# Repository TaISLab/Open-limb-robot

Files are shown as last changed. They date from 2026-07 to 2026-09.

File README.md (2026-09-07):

# Open-Limb Robot

Open, non-anthropomorphic robot that orbits around a compliant cylindrical surface — such as a human limb or a pipe — with a three-contact grasp: a central traction module with two in-line driven wheels, and two lateral spring-loaded arms with distal wheels.

This repository accompanies the paper:

> L. M. Tobar-Subia-Contento, J. A. Cabrera, A. Mandow, and J. M. Gómez-de-Gabriel, "On-Limb Orbiting Robot: Proprioceptive Diameter Estimation and Orthogonal Grip–Orbit Control," submitted to *Biomimetics* (MDPI), 2026.

The central contribution is an actuation-space decomposition in which the two lateral wheel torques, expressed in a common-mode/differential basis, simultaneously drive the orbital motion and regulate the central normal force — orthogonally and without a dedicated force mechanism. The same compliant arms yield a closed-form estimate of the cylinder diameter from proprioception alone.

## Demonstration video

<video src="https://github.com/TaISLab/Open-limb-robot/raw/main/media/On-Limb-Orbiting-Robot.mp4" controls width="600"></video>

## Repository structure

```
Open-limb-robot/
├── CAD/                      # SolidWorks design files and STL/STEP exports
├── experiments/              # Data and processing scripts from the prototype tests
├── simulation/
│   ├── lib/                  # Shared geometry functions
│   └── scripts/              # Runnable analysis scripts
├── media/                    # Demonstration video and funding logo
├── LICENSE
└── README.md
```

### `CAD/`
SolidWorks design files for the Mobile Platform (MP), the central traction module and the lateral grasping arms, plus exported files ready for 3D printing in PETG. Mechanical design parameters are listed in Table 1 of the paper.

### `simulation/`

`lib/` contains the shared geometry functions used by all scripts:

| Function | Implements |
|---|---|
| `contactDepth.m` | Averaged central contact depth, Eq. (1) |
| `radiusEstimator.m` | Closed-form cylinder-radius estimator, Eq. (3) |
| `lateralContactAngle.m` | Lateral-contact angle γ, Eq. (4) |
| `solveArmAngle.m` | Numerical inversion of Eq. (3) for a known radius |

`scripts/` contains the runnable analyses:

| Script | Reproduces |
|---|---|
| `static_force_model_01.m` | Static force model and actuation-space decomposition (Sections 4–5); numerically verifies that the common-mode/differential basis diagonalises the force map, Eq. (20) |
| `orbital_simulation_02.m` | Closed-loop orbital simulation over a full revolution (Section 8.3, Figure 9, Table 2) |
| `radius_estimator_sensitivity_03.m` | Radius-estimator sensitivity analysis (Sections 4.3 and 8.2, Figure 8) |

Scripts add `../lib` to the path automatically. Run them from the `simulation/scripts/` folder.

**Reproducing the feedforward-only vs. feedforward+PI comparison (Table 2).** In `orbital_simulation_02.m`, set the `has_force_sensor` flag to `false` to disable the PI correction and to `true` for the nominal configuration reported in Figure 9.

### `experiments/`
Data and processing scripts from the preliminary prototype tests (Section 8.4): spring characteristic and contact-force calibration (Figure 7), grasp-retention test across orbital orientations (Figure 10), and open-loop orbital-rotation tests for different assumed friction coefficients (Figure 11).

## Hardware

- Actuation: DYNAMIXEL XC330-T288-T servo (grasping actuator), DC motors (drive wheels)
- Sensing: rotational springs with angular sensors (central compliant contact), servo encoder (arm angle), IMU (orbital angle)
- Chassis: 3D-printed PETG

## Requirements

MATLAB (developed with R2023b or later; no toolboxes beyond base MATLAB are required). The scripts also run under GNU Octave.

For CAD source files, SolidWorks; the exported STL/STEP files can be opened with any standard CAD viewer.

## Citation

If you use this code or design in your research, please cite the paper above. A full citation with DOI will be added once the manuscript is published.

## License

Released under the [MIT License](LICENSE).

## Funding

<p align="center">
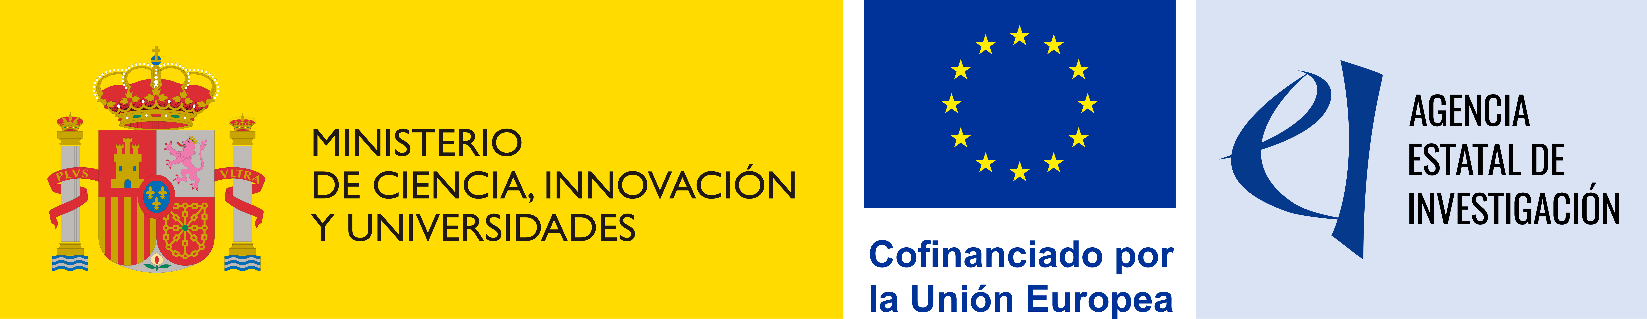
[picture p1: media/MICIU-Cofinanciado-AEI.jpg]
MICIU / AEI / FEDER
  
</p>

<p align="center">
This work is part of project PID2021-127221OB-I00 (CONCERTO — Control Colaborativo para Interacción física Empática entre RoboT y humanO), funded by MICIU/AEI/10.13039/501100011033/FEDER, UE.
</p>

## Contact

Jesús M. Gómez-de-Gabriel — jesus.gomez@uma.es
Institute for Mechatronics Engineering and Cyber-Physical Systems (IMECH.UMA), Universidad de Málaga

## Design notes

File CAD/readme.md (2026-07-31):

============================================================
README – CAD MODEL OF THE ON-LIMB ORBITING ROBOT
============================================================

1. RESOURCE TITLE

CAD model and complete mechanical assembly of the On-Limb
Orbiting Robot.

2. ASSOCIATED PUBLICATION

On-Limb Orbiting Robot: Proprioceptive Diameter Estimation
and Orthogonal Grip–Orbit Control

3. AUTHORS

Luz M. Tobar-Subia-Contento
Juan A. Cabrera
Anthony Mandow
Jesús M. Gómez-de-Gabriel

4. AFFILIATIONS

Faculty of Engineering in Applied Sciences (FICA),
Universidad Técnica del Norte, Ibarra, Ecuador.

Institute for Mechatronics Engineering and Cyber-Physical
Systems (IMECH.UMA), Universidad de Málaga, Málaga, Spain.

5. GENERAL DESCRIPTION

This resource contains the complete mechanical assembly of
the on-limb orbiting robot described in the associated
publication.

The complete assembly and its referenced component files are
provided in the following compressed archive:

OnLimbOrbitalRobot.zip

The original and official file names used during the
development of the robot have been preserved.

6. SOFTWARE USED

Software: SOLIDWORKS 2024
Edition: Academic Edition
Software licence: Academic licence provided by Universidad
de Málaga.

7. FILE ORGANIZATION

The file OnLimbOrbitalRobot.zip contains the complete
mechanical assembly and its associated component files.

Users should preserve the original directory structure and
file names when extracting the archive, as changing their
names or locations may affect the references between the
assembly and its components.

8. INSTRUCTIONS FOR USE

1. Download and extract the complete compressed archive.
2. Preserve the original directory structure.
3. Open the main assembly file using SOLIDWORKS 2024 or a
   compatible version.
4. Allow SOLIDWORKS to resolve the referenced component files
   from the extracted directory.

9. COMPATIBILITY

The files were created and verified using SOLIDWORKS 2024,
Academic Edition.

Compatibility with earlier SOLIDWORKS versions is not
guaranteed. Opening the files with a later version may update
their internal format and prevent subsequent use with
SOLIDWORKS 2024.

10. PURPOSE

The CAD files are provided to support the understanding,
inspection and reproducibility of the mechanical design
presented in the associated scientific publication.

11. RELATED DATASET

The experimental data associated with the validation of the
robot are available in the corresponding RIUMA dataset record.

RIUMA persistent identifier:
[TO BE ASSIGNED BY RIUMA]

12. REUSE LICENCE

The reuse licence for this resource will be specified in the
corresponding RIUMA repository record.

13. CONTACT

Luz M. Tobar-Subia-Contento
Universidad Técnica del Norte / Universidad de Málaga
E-mail: luztobar@uma.es
E-mail: lmtobarsubia@utn.edu.ec

Jesús M. Gómez-de-Gabriel
Universidad de Málaga
E-mail: jesus.gomez@uma.es

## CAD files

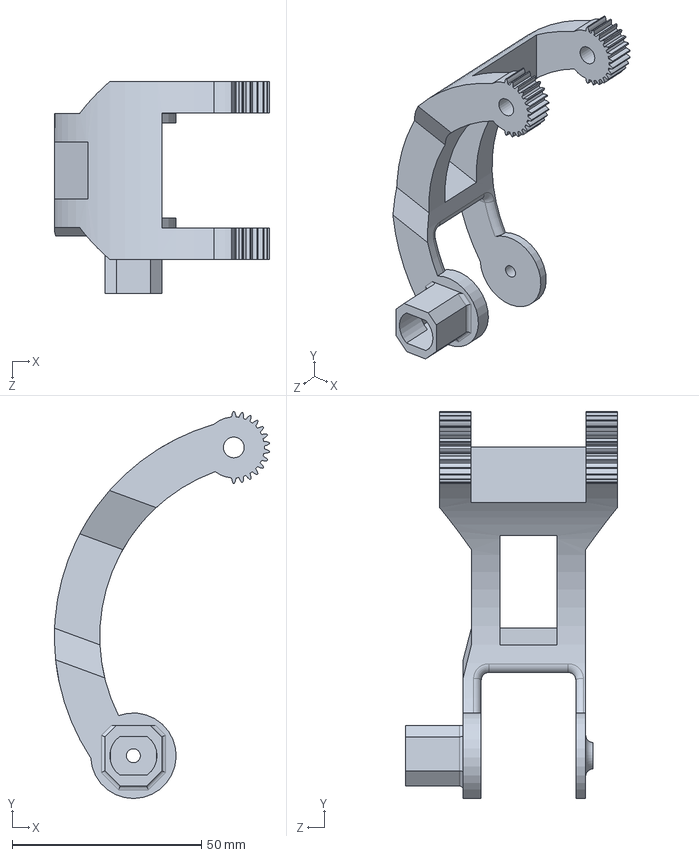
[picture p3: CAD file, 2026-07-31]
CAD/SolidWorks/arm-right.SLDPRT
56.9 x 102.3 x 56.0 mm

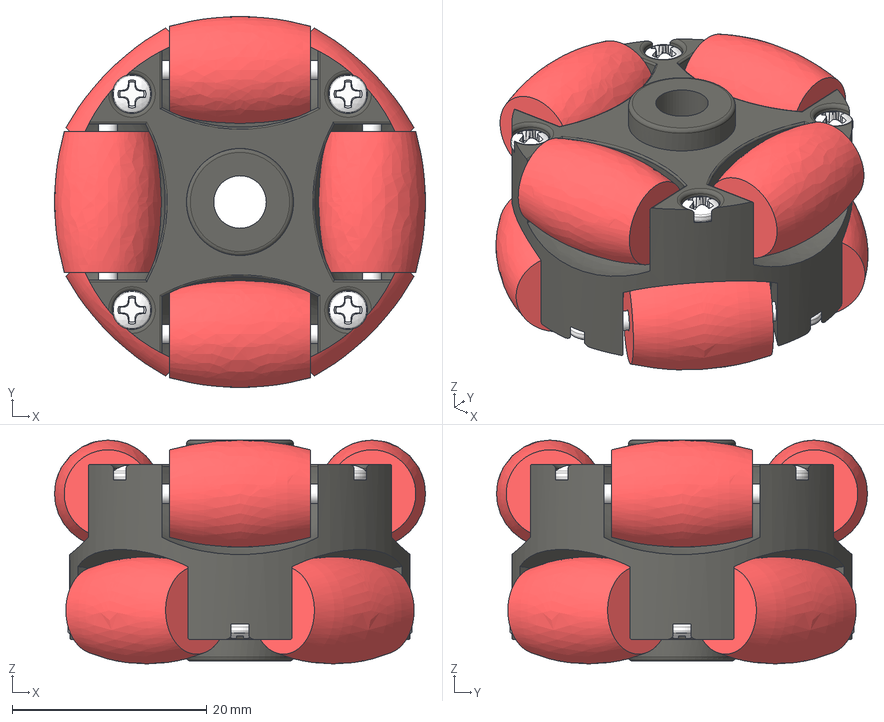
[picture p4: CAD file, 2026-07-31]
CAD/SolidWorks/omni wheel.step
38.1 x 38.1 x 23.0 mm
ролик x 8
92005A010_Steel Pan Head Phillips Screw x 8

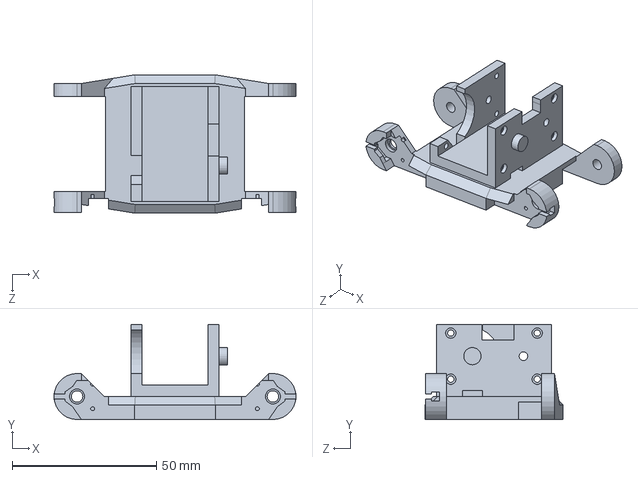
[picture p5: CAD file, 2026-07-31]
CAD/SolidWorks/MobilePlatform.SLDPRT
84.0 x 33.0 x 48.0 mm

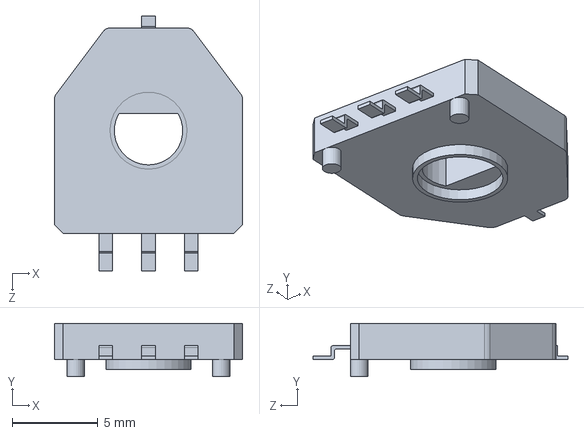
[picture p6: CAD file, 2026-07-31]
CAD/SolidWorks/MurataSV01.SLDPRT
11.0 x 3.10 x 14.9 mm

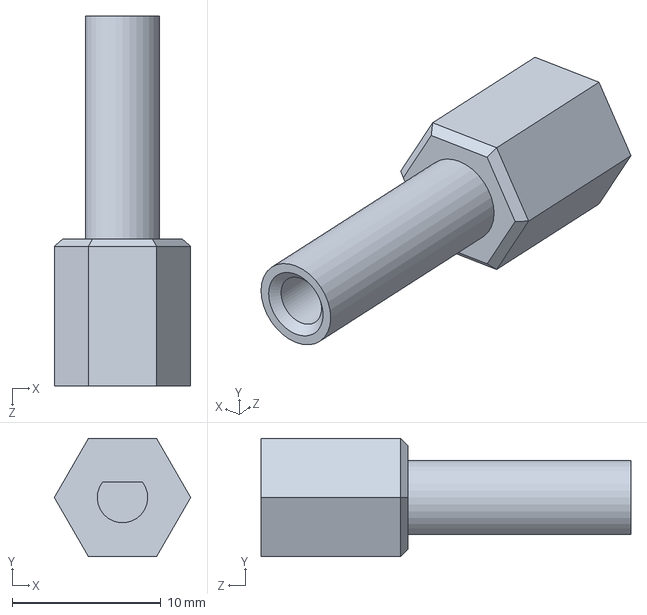
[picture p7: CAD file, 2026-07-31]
CAD/SolidWorks/hub-wheel-minimotor-metal.SLDPRT
9.18 x 7.95 x 24.9 mm

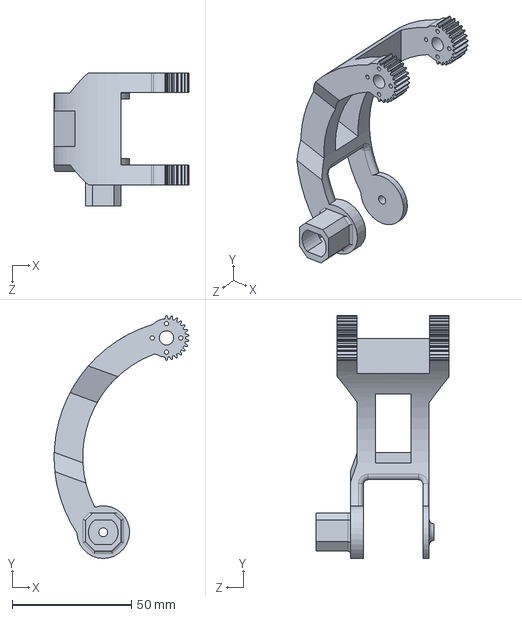
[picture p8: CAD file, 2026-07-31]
CAD/SolidWorks/arm-left.SLDPRT
56.5 x 101.9 x 56.0 mm

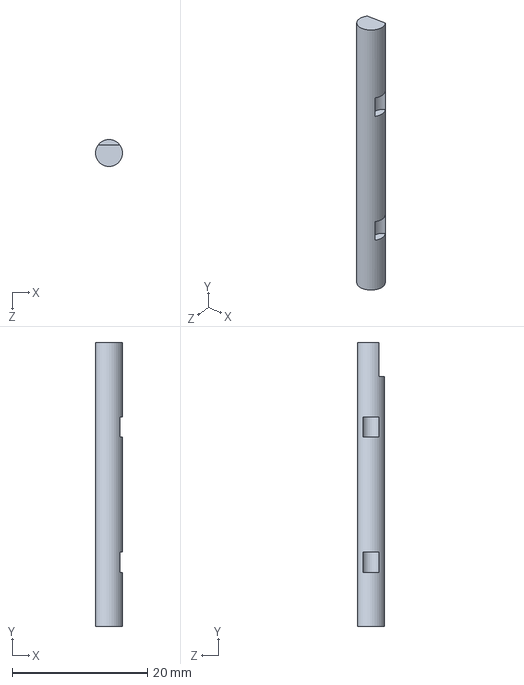
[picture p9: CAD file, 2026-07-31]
CAD/SolidWorks/eje 35x4.SLDPRT
3.98 x 42.0 x 4.00 mm

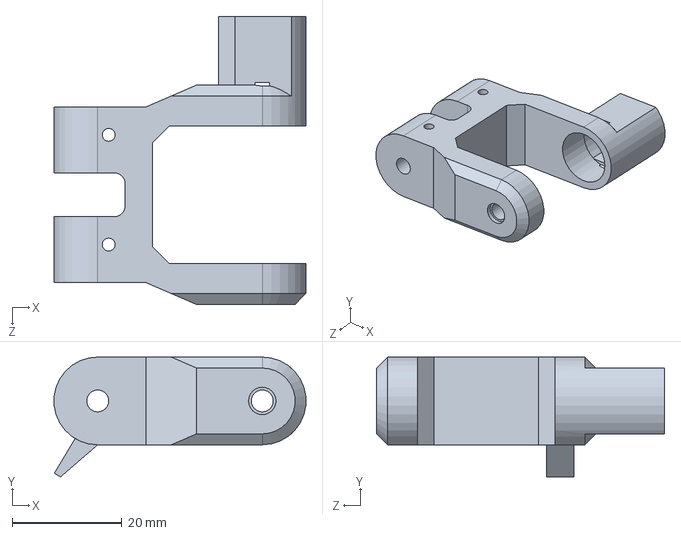
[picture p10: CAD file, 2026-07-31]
CAD/SolidWorks/SwingLinks.SLDPRT
45.9 x 21.9 x 52.5 mm

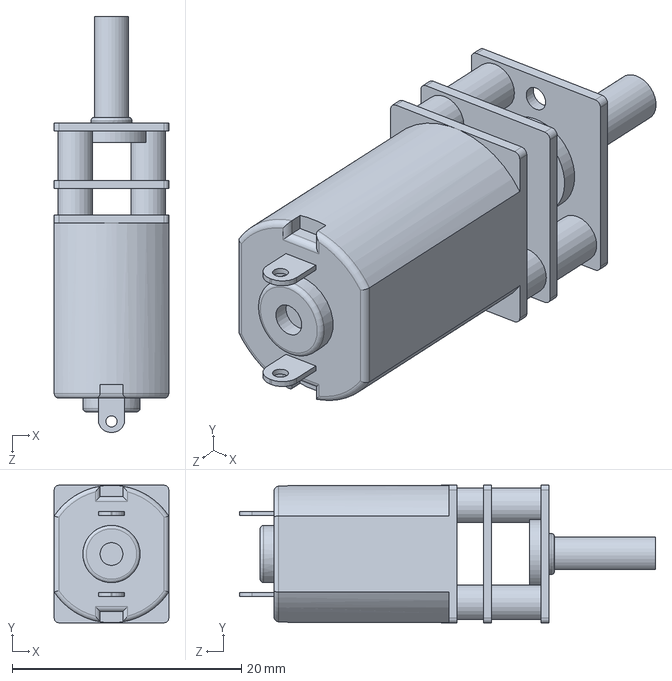
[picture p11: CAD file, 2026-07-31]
CAD/SolidWorks/MicromotorDC.SLDPRT
10.0 x 12.0 x 36.3 mm

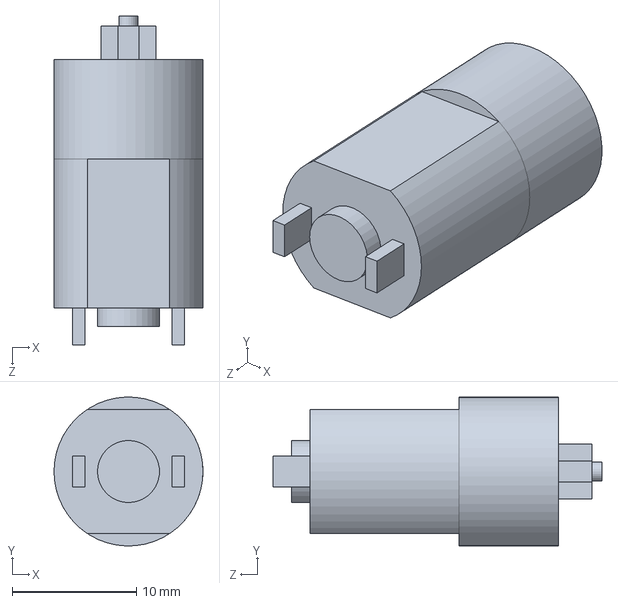
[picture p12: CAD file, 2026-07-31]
CAD/SolidWorks/motorDC_SwingLinks.SLDPRT
12.0 x 12.0 x 26.5 mm

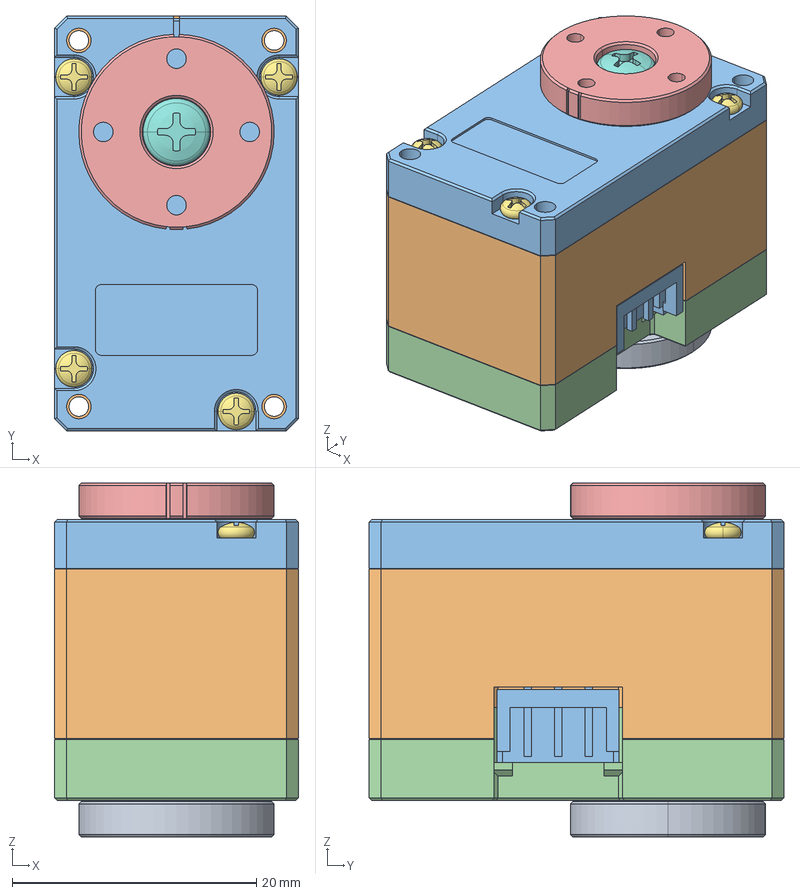
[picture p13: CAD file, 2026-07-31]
CAD/SolidWorks/XL,XC-330.stp
20.0 x 34.0 x 29.0 mm
DC15_A01_CASE_M_DUMMY
DC15_A01_CASE_F_DUMMY
DC15_A01_CASE_B_DUMMY
DC15_A01_HORN_DUMMY
DC15_A01_LED_CAP2_DUMMY
PHS_1_7X20_5_DC10 x 4
BTS2_M2_6X8 x 2
DC15_A01_HORN_IDLE2_DUMMY
DC15_A01_IDLE_CAP_DUMMY
B3B-EH x 2

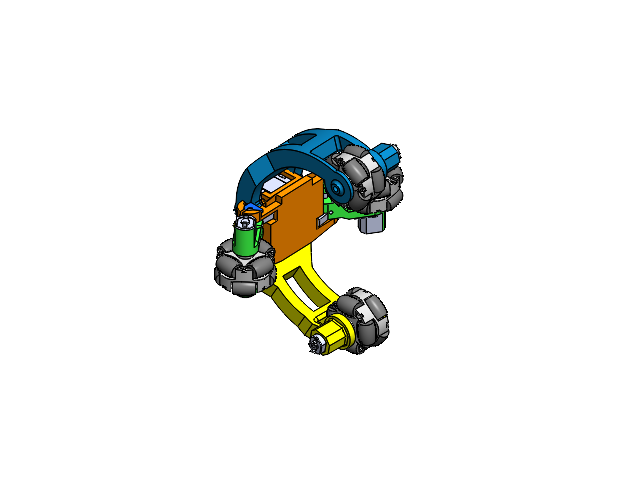
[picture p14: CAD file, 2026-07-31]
CAD/SolidWorks/OnLimbOrbitalRobot.SLDASM
arm-right
ролик.step x 32
92005A010_Steel Pan Head Phillips Screw.step x 32
колесо.step x 4
колесо-0.step x 4
колесо-1.step x 4
колесо-2.step x 4
колесо-3.step x 4
колесо-4.step x 4
колесо-5.step x 4
колесо-6.step x 4
колесо-7.step x 4
MobilePlatform
SwingLinks x 2
eje 35x4 x 2
MurataSV01 x 2
DC15_A01_CASE_M_DUMMY.stp
DC15_A01_CASE_F_DUMMY.stp
DC15_A01_CASE_B_DUMMY.stp
DC15_A01_HORN_DUMMY.stp
DC15_A01_LED_CAP2_DUMMY.stp
PHS_1_7X20_5_DC10.stp x 4
BTS2_M2_6X8.stp x 2
DC15_A01_HORN_IDLE2_DUMMY.stp
DC15_A01_IDLE_CAP_DUMMY.stp
B3B-EH_1.stp x 2
arm-left
motorDC_SwingLinks x 2
hub-wheel-minimotor-metal x 2
MicromotorDC x 2

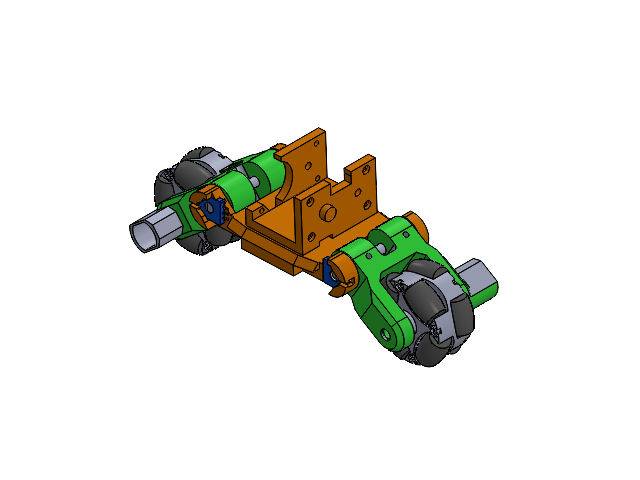
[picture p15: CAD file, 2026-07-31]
CAD/SolidWorks/CentraTractionModule.SLDASM
MobilePlatform
SwingLinks x 2
ролик.step x 16
92005A010_Steel Pan Head Phillips Screw.step x 16
колесо.step x 2
колесо-0.step x 2
колесо-1.step x 2
колесо-2.step x 2
колесо-3.step x 2
колесо-4.step x 2
колесо-5.step x 2
колесо-6.step x 2
колесо-7.step x 2
eje 35x4 x 2
MurataSV01 x 2

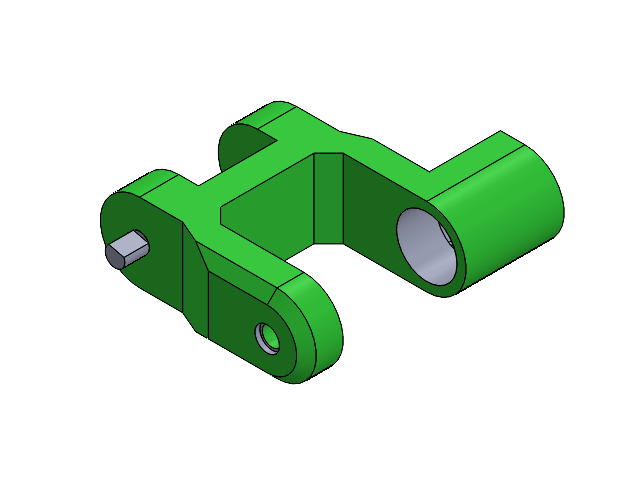
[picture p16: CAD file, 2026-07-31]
CAD/SolidWorks/SuspentionSystem.SLDASM
basculante lateral
ролик.step x 8
92005A010_Steel Pan Head Phillips Screw.step x 8
колесо.step
колесо-0.step
колесо-1.step
колесо-2.step
колесо-3.step
колесо-4.step
колесо-5.step
колесо-6.step
колесо-7.step
eje 35x4

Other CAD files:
CAD/SolidWorks/XL,XC-330.SLDASM
CAD/SolidWorks/omni wheel.SLDASM

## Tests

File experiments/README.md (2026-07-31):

## Dependencies

- MATLAB
- Arduino IDE
- Dynamixel SDK for MATLAB (Jonathon / ROBOTIS)
- Dynamixel USB interface

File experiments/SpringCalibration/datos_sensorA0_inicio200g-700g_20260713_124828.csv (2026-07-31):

Tiempo_s | ADC | Voltaje_V | Bloque | PesoProgramado_kg
0.000 | 509 | 2.487781 | 0 | 0.000000
0.100 | 509 | 2.487781 | 0 | 0.000000
0.200 | 508 | 2.482893 | 0 | 0.000000
0.300 | 508 | 2.482893 | 0 | 0.000000
0.400 | 509 | 2.487781 | 0 | 0.000000
0.500 | 508 | 2.482893 | 0 | 0.000000
0.600 | 508 | 2.482893 | 0 | 0.000000
0.700 | 509 | 2.487781 | 0 | 0.000000
0.800 | 508 | 2.482893 | 0 | 0.000000
0.900 | 508 | 2.482893 | 0 | 0.000000
1.000 | 509 | 2.487781 | 0 | 0.000000
1.100 | 509 | 2.487781 | 0 | 0.000000
1.200 | 509 | 2.487781 | 0 | 0.000000
1.300 | 508 | 2.482893 | 0 | 0.000000
1.400 | 508 | 2.482893 | 0 | 0.000000
1.500 | 509 | 2.487781 | 0 | 0.000000
1.600 | 508 | 2.482893 | 0 | 0.000000
1.700 | 509 | 2.487781 | 0 | 0.000000
1.800 | 509 | 2.487781 | 0 | 0.000000
1.900 | 509 | 2.487781 | 0 | 0.000000
2.000 | 509 | 2.487781 | 0 | 0.000000
2.100 | 508 | 2.482893 | 0 | 0.000000
2.200 | 508 | 2.482893 | 0 | 0.000000
2.300 | 509 | 2.487781 | 0 | 0.000000
2.400 | 508 | 2.482893 | 0 | 0.000000
2.500 | 508 | 2.482893 | 0 | 0.000000
2.600 | 508 | 2.482893 | 0 | 0.000000
2.700 | 508 | 2.482893 | 0 | 0.000000
2.800 | 509 | 2.487781 | 0 | 0.000000
2.900 | 508 | 2.482893 | 0 | 0.000000
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

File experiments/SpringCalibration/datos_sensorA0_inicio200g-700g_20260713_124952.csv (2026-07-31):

Tiempo_s | ADC | Voltaje_V | Bloque | PesoProgramado_kg
0.000 | 504 | 2.463343 | 0 | 0.000000
0.100 | 503 | 2.458456 | 0 | 0.000000
0.200 | 503 | 2.458456 | 0 | 0.000000
0.300 | 503 | 2.458456 | 0 | 0.000000
0.400 | 503 | 2.458456 | 0 | 0.000000
0.500 | 503 | 2.458456 | 0 | 0.000000
0.600 | 503 | 2.458456 | 0 | 0.000000
0.700 | 503 | 2.458456 | 0 | 0.000000
0.800 | 503 | 2.458456 | 0 | 0.000000
0.901 | 503 | 2.458456 | 0 | 0.000000
1.000 | 503 | 2.458456 | 0 | 0.000000
1.100 | 503 | 2.458456 | 0 | 0.000000
1.200 | 503 | 2.458456 | 0 | 0.000000
1.300 | 503 | 2.458456 | 0 | 0.000000
1.400 | 503 | 2.458456 | 0 | 0.000000
1.500 | 504 | 2.463343 | 0 | 0.000000
1.600 | 503 | 2.458456 | 0 | 0.000000
1.700 | 503 | 2.458456 | 0 | 0.000000
1.800 | 503 | 2.458456 | 0 | 0.000000
1.900 | 503 | 2.458456 | 0 | 0.000000
2.000 | 504 | 2.463343 | 0 | 0.000000
2.100 | 503 | 2.458456 | 0 | 0.000000
2.200 | 503 | 2.458456 | 0 | 0.000000
2.300 | 503 | 2.458456 | 0 | 0.000000
2.400 | 503 | 2.458456 | 0 | 0.000000
2.500 | 503 | 2.458456 | 0 | 0.000000
2.600 | 503 | 2.458456 | 0 | 0.000000
2.700 | 503 | 2.458456 | 0 | 0.000000
2.800 | 503 | 2.458456 | 0 | 0.000000
2.900 | 503 | 2.458456 | 0 | 0.000000
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

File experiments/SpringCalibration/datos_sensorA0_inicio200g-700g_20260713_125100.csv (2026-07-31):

Tiempo_s | ADC | Voltaje_V | Bloque | PesoProgramado_kg
0.000 | 501 | 2.448680 | 0 | 0.000000
0.100 | 501 | 2.448680 | 0 | 0.000000
0.200 | 501 | 2.448680 | 0 | 0.000000
0.300 | 501 | 2.448680 | 0 | 0.000000
0.400 | 501 | 2.448680 | 0 | 0.000000
0.500 | 501 | 2.448680 | 0 | 0.000000
0.600 | 501 | 2.448680 | 0 | 0.000000
0.701 | 501 | 2.448680 | 0 | 0.000000
0.800 | 501 | 2.448680 | 0 | 0.000000
0.900 | 501 | 2.448680 | 0 | 0.000000
1.000 | 501 | 2.448680 | 0 | 0.000000
1.100 | 501 | 2.448680 | 0 | 0.000000
1.200 | 501 | 2.448680 | 0 | 0.000000
1.300 | 501 | 2.448680 | 0 | 0.000000
1.400 | 501 | 2.448680 | 0 | 0.000000
1.500 | 501 | 2.448680 | 0 | 0.000000
1.600 | 501 | 2.448680 | 0 | 0.000000
1.700 | 501 | 2.448680 | 0 | 0.000000
1.800 | 501 | 2.448680 | 0 | 0.000000
1.900 | 501 | 2.448680 | 0 | 0.000000
2.000 | 501 | 2.448680 | 0 | 0.000000
2.100 | 501 | 2.448680 | 0 | 0.000000
2.200 | 501 | 2.448680 | 0 | 0.000000
2.300 | 501 | 2.448680 | 0 | 0.000000
2.400 | 501 | 2.448680 | 0 | 0.000000
2.500 | 501 | 2.448680 | 0 | 0.000000
2.600 | 501 | 2.448680 | 0 | 0.000000
2.700 | 501 | 2.448680 | 0 | 0.000000
2.800 | 501 | 2.448680 | 0 | 0.000000
2.900 | 501 | 2.448680 | 0 | 0.000000
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

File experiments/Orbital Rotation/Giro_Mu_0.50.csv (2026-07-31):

Tiempo_s | Phi_rel_deg | Phi_raw_deg | AX_g | AY_g | AZ_g | A0_V | A2_V | Theta0_raw | Theta0_filtrado | DXL_Corriente_mA | DXL_Corriente_abs_mA | DXL_Posicion_pulsos | DXL_Posicion_deg | DXL_Goal_Position_deg | Pulsos_Objetivo | Edad_dato_Arduino_s | Tau_calculado_Nmm | Corriente_calculada_mA | Test_ID | Motivo_detencion
0.000269586 | 4.22189162667941 | 10.387 | 0.4792 | -0.0085 | 1.0325 | 2.683 | 2.278 | 1.32696087626722 | 1.32696087626722 | -170 | 170 | 1889 | 166.025390625 | 127.265625 | 0 | 0 | 6.1520536592641 | 142.740916225447 | Giro_Off_intento5_180deg_2000_pulsos_Mu_0.50 | TIEMPO_MAXIMO
0.060174286 | 4.90289162667941 | 11.068 | 0.5554 | 0.0325 | 0.9949 | 2.678 | 2.297 | 1.33680909543189 | 1.32942293105839 | -146 | 146 | 1889 | 166.025390625 | 127.265625 | 255 | 0 | 10.3608510678253 | 146.400740058979 | Giro_Off_intento5_180deg_2000_pulsos_Mu_0.50 | TIEMPO_MAXIMO
0.130421017 | 5.80889162667941 | 11.974 | 0.5171 | -0.0154 | 1.0347 | 2.678 | 2.307 | 1.33680909543189 | 1.33126947215176 | -149 | 149 | 1889 | 166.025390625 | 127.265625 | 255 | 0 | 15.9534701547847 | 151.263887091117 | Giro_Off_intento5_180deg_2000_pulsos_Mu_0.50 | TIEMPO_MAXIMO
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

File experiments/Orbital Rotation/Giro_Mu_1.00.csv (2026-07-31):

Tiempo_s | Phi_rel_deg | Phi_raw_deg | AX_g | AY_g | AZ_g | A0_V | A2_V | Theta0_raw | Theta0_filtrado | DXL_Corriente_mA | DXL_Corriente_abs_mA | DXL_Posicion_pulsos | DXL_Posicion_deg | DXL_Goal_Position_deg | Pulsos_Objetivo | Edad_dato_Arduino_s | Tau_calculado_Nmm | Corriente_calculada_mA | Test_ID | Motivo_detencion
0.000142116 | 3.17165291102728 | 10.377 | 0.4646 | -0.012 | 1.0271 | 2.678 | 2.258 | 1.48604499845895 | 1.48604499845895 | -139 | 139 | 1891 | 166.201171875 | 127.44140625 | 0 | 0 | 9.82710586343877 | 128.545309446469 | Giro_Off_intento4_180deg_2000_pulsos_Mu_1.00 | TIEMPO_MAXIMO
0.055760852 | 3.99265291102728 | 11.198 | 0.5815 | -0.0212 | 1.0254 | 2.674 | 2.263 | 1.49741447210711 | 1.48888736687099 | -130 | 130 | 1891 | 166.201171875 | 127.44140625 | 255 | 0 | 12.3672122446618 | 130.754097604054 | Giro_Off_intento4_180deg_2000_pulsos_Mu_1.00 | TIEMPO_MAXIMO
0.103741667 | 4.89765291102728 | 12.103 | 0.4856 | -0.0093 | 1.022 | 2.678 | 2.268 | 1.48604499845895 | 1.48817677476798 | -131 | 131 | 1891 | 166.201171875 | 127.44140625 | 255 | 0 | 15.1642448704303 | 133.186299887331 | Giro_Off_intento4_180deg_2000_pulsos_Mu_1.00 | TIEMPO_MAXIMO
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

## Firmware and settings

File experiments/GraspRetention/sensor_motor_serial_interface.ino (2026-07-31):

#include <Wire.h>

// ========================================================
// PINES
// ========================================================
const int IN1 = 6;
const int IN2 = 7;
const int IN3 = 11;
const int IN4 = 10;

const int ENC1_A = 2;
const int ENC1_B = 4;
const int ENC2_A = 3;
const int ENC2_B = 5;

// ========================================================
// VARIABLES GLOBALES: CONTROL EN BUCLE ABIERTO Y ESTADO
// ========================================================
volatile long encoder1Pos = 0;
volatile long encoder2Pos = 0;

uint8_t mpuAddress = 0;

bool motorsActive = false;

// Se conserva para mantener la compatibilidad con el comando START.
// En bucle abierto, únicamente se utiliza su signo para definir el sentido.
long targetPos = 0;

// 1 = Ida, -1 = Retorno
int currentDirection = 1;

// PWM constante aplicado durante las pruebas en bucle abierto
const int FIXED_PWM = 255;

float phi_complementario = 0.0;

unsigned long lastTime = 0;

// Intervalo de actualización del accionamiento y la telemetría [ms]
const unsigned long CONTROL_INTERVAL = 10;

// ========================================================
// FUNCIONES DE COMUNICACIÓN I2C
// ========================================================
bool escribirRegistro(
  uint8_t direccion,
  uint8_t registro,
  uint8_t valor
) {
  Wire.beginTransmission(direccion);
  Wire.write(registro);
  Wire.write(valor);

  return Wire.endTransmission() == 0;
}

bool leerRegistro(
  uint8_t direccion,
  uint8_t registro,
  uint8_t &valor
) {
  Wire.beginTransmission(direccion);
  Wire.write(registro);

  if (Wire.endTransmission(false) != 0) {
    return false;
  }

  if (Wire.requestFrom(direccion, (uint8_t)1) != 1) {
    return false;
  }

  valor = Wire.read();
  return true;
}

// ========================================================
// INTERRUPCIONES DE LOS ENCODERS
// ========================================================
void readEncoder1() {
  if (digitalRead(ENC1_B) == HIGH) {
    encoder1Pos++;
  } else {
    encoder1Pos--;
  }
}

void readEncoder2() {
  if (digitalRead(ENC2_B) == HIGH) {
    encoder2Pos++;
  } else {
    encoder2Pos--;
  }
}

// ========================================================
// CONFIGURACIÓN INICIAL
// ========================================================
void setup() {
  Serial.begin(115200);

  pinMode(IN1, OUTPUT);
  pinMode(IN2, OUTPUT);
  pinMode(IN3, OUTPUT);
  pinMode(IN4, OUTPUT);

  stopAllMotors();

  pinMode(ENC1_A, INPUT_PULLUP);
  pinMode(ENC2_A, INPUT_PULLUP);

  attachInterrupt(
    digitalPinToInterrupt(ENC1_A),
    readEncoder1,
    RISING
  );

  attachInterrupt(
    digitalPinToInterrupt(ENC2_A),
    readEncoder2,
    RISING
  );

  Wire.begin();
  Wire.setClock(100000);

  if (!detectarMPU6050()) {
    // El programa permanece bloqueado si no se detecta el sensor.
    while (true) {
      delay(1000);
    }
  }

  escribirRegistro(
    mpuAddress,
    0x6B,
    0x00
  );  // Activar el MPU6050

  escribirRegistro(
    mpuAddress,
    0x1C,
    0x00
  );  // Configurar el acelerómetro en ±2 g
}

// ========================================================
// BUCLE PRINCIPAL
// ========================================================
void loop() {
  unsigned long currentTime = millis();

  checkSerialCommands();

  if (currentTime - lastTime >= CONTROL_INTERVAL) {
    lastTime = currentTime;

    int appliedPWM = 0;

    if (motorsActive) {
      // Funcionamiento en bucle abierto:
      // el PWM no depende de los encoders ni de un error de posición.
      appliedPWM = currentDirection * FIXED_PWM;

      setMotorPWM(1, appliedPWM);
      setMotorPWM(2, appliedPWM);
    } else {
      stopAllMotors();
    }

    // Se transmite el PWM realmente aplicado.
    sendTelemetry(appliedPWM);
  }
}

// ========================================================
// CONTROL DE MOTORES: PWM FIJO CON SIGNO
// ========================================================
void setMotorPWM(
  int motorNum,
  float controlSignal
) {
  int pwm = constrain(
    (int)controlSignal,
    -255,
    255
  );

  if (abs(pwm) < 25) {
    pwm = 0;
  }

  if (motorNum == 1) {
    // Desactivar inicialmente ambas entradas del motor 1.
    digitalWrite(IN1, LOW);
    digitalWrite(IN2, LOW);

    // Aplicar el sentido de giro correspondiente.
    if (pwm >= 0) {
      analogWrite(IN1, pwm);
    } else {
      analogWrite(IN2, abs(pwm));
    }
  } else {
    // Desactivar inicialmente ambas entradas del motor 2.
    digitalWrite(IN3, LOW);
    digitalWrite(IN4, LOW);

    // Aplicar el sentido de giro correspondiente.
    if (pwm >= 0) {
      analogWrite(IN3, pwm);
    } else {
      analogWrite(IN4, abs(pwm));
    }
  }
}

void stopAllMotors() {
  digitalWrite(IN1, LOW);
  digitalWrite(IN2, LOW);
  digitalWrite(IN3, LOW);
  digitalWrite(IN4, LOW);
}

// ========================================================
// TELEMETRÍA
// FILTRO COMPLEMENTARIO CONTINUO CON UNWRAPPING ANGULAR
// ========================================================
void sendTelemetry(int appliedPWM) {
  int16_t axRaw;
  int16_t ayRaw;
  int16_t azRaw;
  int16_t gxRaw;
  int16_t gyRaw;
  int16_t gzRaw;

  float ax = 0.0;
  float ay = 0.0;
  float az = 0.0;

  float dt = CONTROL_INTERVAL / 1000.0;

  if (
    leerMPU(
      axRaw,
      ayRaw,
      azRaw,
      gxRaw,
      gyRaw,
      gzRaw
    )
  ) {
    ax = axRaw / 16384.0;
    ay = ayRaw / 16384.0;
    az = azRaw / 16384.0;

    // 1. Ángulo calculado a partir del acelerómetro [-180, 180].
    float accel_angle =
      atan2(ax, az) * 180.0 / PI;

    // 2. Velocidad angular del giroscopio [deg/s].
    float gyro_rate =
      gyRaw / 131.0;

    // 3. Predicción angular basada en la integración del giroscopio.
    float phi_predicho =
      phi_complementario + (gyro_rate * dt);

    // 4. Diferencia angular limitada al intervalo [-180, 180].
    float diff =
      accel_angle - phi_predicho;

    diff = fmod(
      diff + 180.0,
      360.0
    );

    if (diff < 0) {
      diff += 360.0;
    }

    diff -= 180.0;

    // 5. Actualización continua del filtro complementario.
    phi_complementario =
      phi_predicho + (0.02 * diff);
  }

  // Lectura de las entradas analógicas.
  float a0_real =
    analogRead(A0) * (5.0 / 1023.0);

  float a2_real =
    analogRead(A2) * (5.0 / 1023.0);

  int pwmRegistro = constrain(
    appliedPWM,
    -255,
    255
  );

  // Telemetría enviada a MATLAB.
  Serial.print("AX_g:");
  Serial.print(ax, 4);
  Serial.print(" ");

  Serial.print("AY_g:");
  Serial.print(ay, 4);
  Serial.print(" ");

  Serial.print("AZ_g:");
  Serial.print(az, 4);
  Serial.print(" ");

  Serial.print("A0_V:");
  Serial.print(a0_real, 3);
  Serial.print(" ");

  Serial.print("A2_V:");
  Serial.print(a2_real, 3);
  Serial.print(" ");

  Serial.print("PWM:");
  Serial.print(pwmRegistro);
  Serial.print(" ");

  Serial.print("PHI_deg:");
  Serial.println(phi_complementario, 3);
}

// ========================================================
// COMANDOS RECIBIDOS DESDE MATLAB
// ========================================================
void checkSerialCommands() {
  if (Serial.available() > 0) {
    String cmd =
      Serial.readStringUntil('\n');

    // Elimina espacios y posibles caracteres '\r'.
    cmd.trim();

    if (cmd.startsWith("START,")) {
      targetPos =
        cmd.substring(6).toInt();

      // En bucle abierto, el signo del valor recibido
      // determina exclusivamente el sentido de giro.
      if (targetPos > 0) {
        currentDirection = 1;
      } else if (targetPos < 0) {
        currentDirection = -1;
      } else {
        motorsActive = false;
        stopAllMotors();
        return;
      }

      // Reinicio de los encoders al comenzar una nueva fase.
      encoder1Pos = 0;
      encoder2Pos = 0;

      motorsActive = true;
    } else if (cmd.equals("STOP")) {
      motorsActive = false;
      stopAllMotors();
    }
  }
}

// ========================================================
// DETECCIÓN DEL MPU6050
// ========================================================
bool detectarMPU6050() {
  const uint8_t direcciones[] = {
    0x68,
    0x69
  };

  for (uint8_t i = 0; i < 2; i++) {
    uint8_t direccion =
      direcciones[i];

    Wire.beginTransmission(direccion);

    if (Wire.endTransmission() == 0) {
      uint8_t whoAmI;

      if (
        leerRegistro(
          direccion,
          0x75,
          whoAmI
        )
      ) {
        Serial.print(
          "Dispositivo encontrado en 0x"
        );
        Serial.println(
          direccion,
          HEX
        );

        Serial.print(
          "Registro WHO_AM_I: 0x"
        );
        Serial.println(
          whoAmI,
          HEX
        );

        if (
          whoAmI == 0x68 ||
          whoAmI == 0x69
        ) {
          mpuAddress = direccion;
          return true;
        }
      }
    }
  }

  return false;
}

// ========================================================
// LECTURA DEL MPU6050
// ========================================================
bool leerMPU(
  int16_t &ax,
  int16_t &ay,
  int16_t &az,
  int16_t &gx,
  int16_t &gy,
  int16_t &gz
) {
  // Comenzar en el registro ACCEL_XOUT_H.
  Wire.beginTransmission(mpuAddress);
  Wire.write(0x3B);

  if (Wire.endTransmission(false) != 0) {
    return false;
  }

  // Solicitar 14 bytes:
  // 6 del acelerómetro, 2 de temperatura y 6 del giroscopio.
  uint8_t recibidos =
    Wire.requestFrom(
      mpuAddress,
      (uint8_t)14
    );

  if (recibidos != 14) {
    return false;
  }

  // Combinar los bytes alto y bajo del acelerómetro.
  ax = (int16_t)(
    (Wire.read() << 8) |
    Wire.read()
  );

  ay = (int16_t)(
    (Wire.read() << 8) |
    Wire.read()
  );

  az = (int16_t)(
    (Wire.read() << 8) |
    Wire.read()
  );

  // Descartar los dos bytes correspondientes a la temperatura.
  Wire.read();
  Wire.read();

  // Combinar los bytes alto y bajo del giroscopio.
  gx = (int16_t)(
    (Wire.read() << 8) |
    Wire.read()
  );

  gy = (int16_t)(
    (Wire.read() << 8) |
    Wire.read()
  );

  gz = (int16_t)(
    (Wire.read() << 8) |
    Wire.read()
  );

  return true;
}

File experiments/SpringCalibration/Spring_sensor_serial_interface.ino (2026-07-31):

/*
  Lectura del sensor conectado en A0
  Arduino Mega 2560

  Formato enviado:
  DATA,tiempo_ms,ADC,voltaje,bloque

  El Arduino espera el comando START enviado desde MATLAB.
*/

const uint8_t SENSOR_PIN = A0;

const unsigned long PERIODO_MUESTREO_MS = 100;  // 10 muestras por segundo
const unsigned long INTERVALO_PESO_MS   = 5000; // Nuevo bloque cada 5 segundos

// Voltaje de referencia nominal del ADC.
// Puede ajustarse después si se mide un valor diferente.
const float VOLTAJE_REFERENCIA = 5.0;

bool adquiriendo = false;

unsigned long tiempoInicio = 0;
unsigned long proximaMuestra = 0;

void setup()
{
  Serial.begin(115200);
  Serial.setTimeout(50);

  pinMode(SENSOR_PIN, INPUT);

  // Mensaje de arranque. MATLAB lo eliminará antes de comenzar.
  Serial.println("ARDUINO_READY");
}

void loop()
{
  revisarComandos();

  if (!adquiriendo)
  {
    return;
  }

  unsigned long tiempoTranscurrido = millis() - tiempoInicio;

  if (tiempoTranscurrido >= proximaMuestra)
  {
    tomarYEnviarMuestra(tiempoTranscurrido);

    proximaMuestra += PERIODO_MUESTREO_MS;

    // Evita acumulaciones si por alguna razón hubo un retraso grande.
    if (tiempoTranscurrido > proximaMuestra + PERIODO_MUESTREO_MS)
    {
      proximaMuestra = tiempoTranscurrido + PERIODO_MUESTREO_MS;
    }
  }
}

void revisarComandos()
{
  if (Serial.available() <= 0)
  {
    return;
  }

  String comando = Serial.readStringUntil('\n');
  comando.trim();

  if (comando == "START")
  {
    tiempoInicio = millis();
    proximaMuestra = 0;
    adquiriendo = true;

    Serial.println("READY");
  }
  else if (comando == "STOP")
  {
    adquiriendo = false;
    Serial.println("STOPPED");
  }
}

void tomarYEnviarMuestra(unsigned long tiempoMs)
{
  int lecturaADC = analogRead(SENSOR_PIN);

  float voltaje =
    lecturaADC * VOLTAJE_REFERENCIA / 1023.0;

  unsigned long bloque =
    tiempoMs / INTERVALO_PESO_MS;

  Serial.print("DATA,");
  Serial.print(tiempoMs);
  Serial.print(",");
  Serial.print(lecturaADC);
  Serial.print(",");
  Serial.print(voltaje, 6);
  Serial.print(",");
  Serial.println(bloque);
}

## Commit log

2026-07-31 Add README for On-Limb Orbiting Robot CAD model
    This README provides detailed information about the CAD model and mechanical assembly of the On-Limb Orbiting Robot, including authors, affiliations, software used, instructions for use, and contact 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
2026-07-31 Add static force model for on-limb orbiting robot
    Implement static contact-force model and actuation-space decomposition for the on-limb orbiting robot. The script reproduces equations from the manuscript and verifies the structural results regardin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
